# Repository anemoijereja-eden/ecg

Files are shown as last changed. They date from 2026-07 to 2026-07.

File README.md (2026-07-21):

E.D.E.N.Tech Open Source Hardware health telemetry system
This project aims to bring the features of medical grade wireless telemetry systems to the people, making them vastly more compact and lowering costs significantly.
Where the average medical grade device that does what this unit can costs hundreds of dollars and only supports proprietary EMR systems, this device uses commodity parts and is intended to connect to an open source telemetry system based on InfluxDB.

Current work completed:
- Signal acquisition using an esp32-s3
- Off device signal processing
- first revision PCB design

To Do:
- Move signal processing onto the device itself
- enable device to report data over the network
- finish PCB designs and create the actual device
- create software solution for processing telemetry data on a recieving server
- Look into other telemetry to integrate

Potential ideas:
- non-invasive blood pressure monitor built more compact than ever before using a PCB motor, integrated cycloidal drive, and a membrane pump to create the full system at a pcb scale.
- integration with implanted sensors via nfc

Tech Stack:
The system is based around the AD8232 as an analog frontend, connected to an ESP32-S3 microcontroller to create a low cost platform using parts that are already widely used and accepted in open hardware.
This repository contains an esp32 firmware, a kicad project under the "PCB" subdirectory, and the prototype off-device processing scripts in "plotter.py"

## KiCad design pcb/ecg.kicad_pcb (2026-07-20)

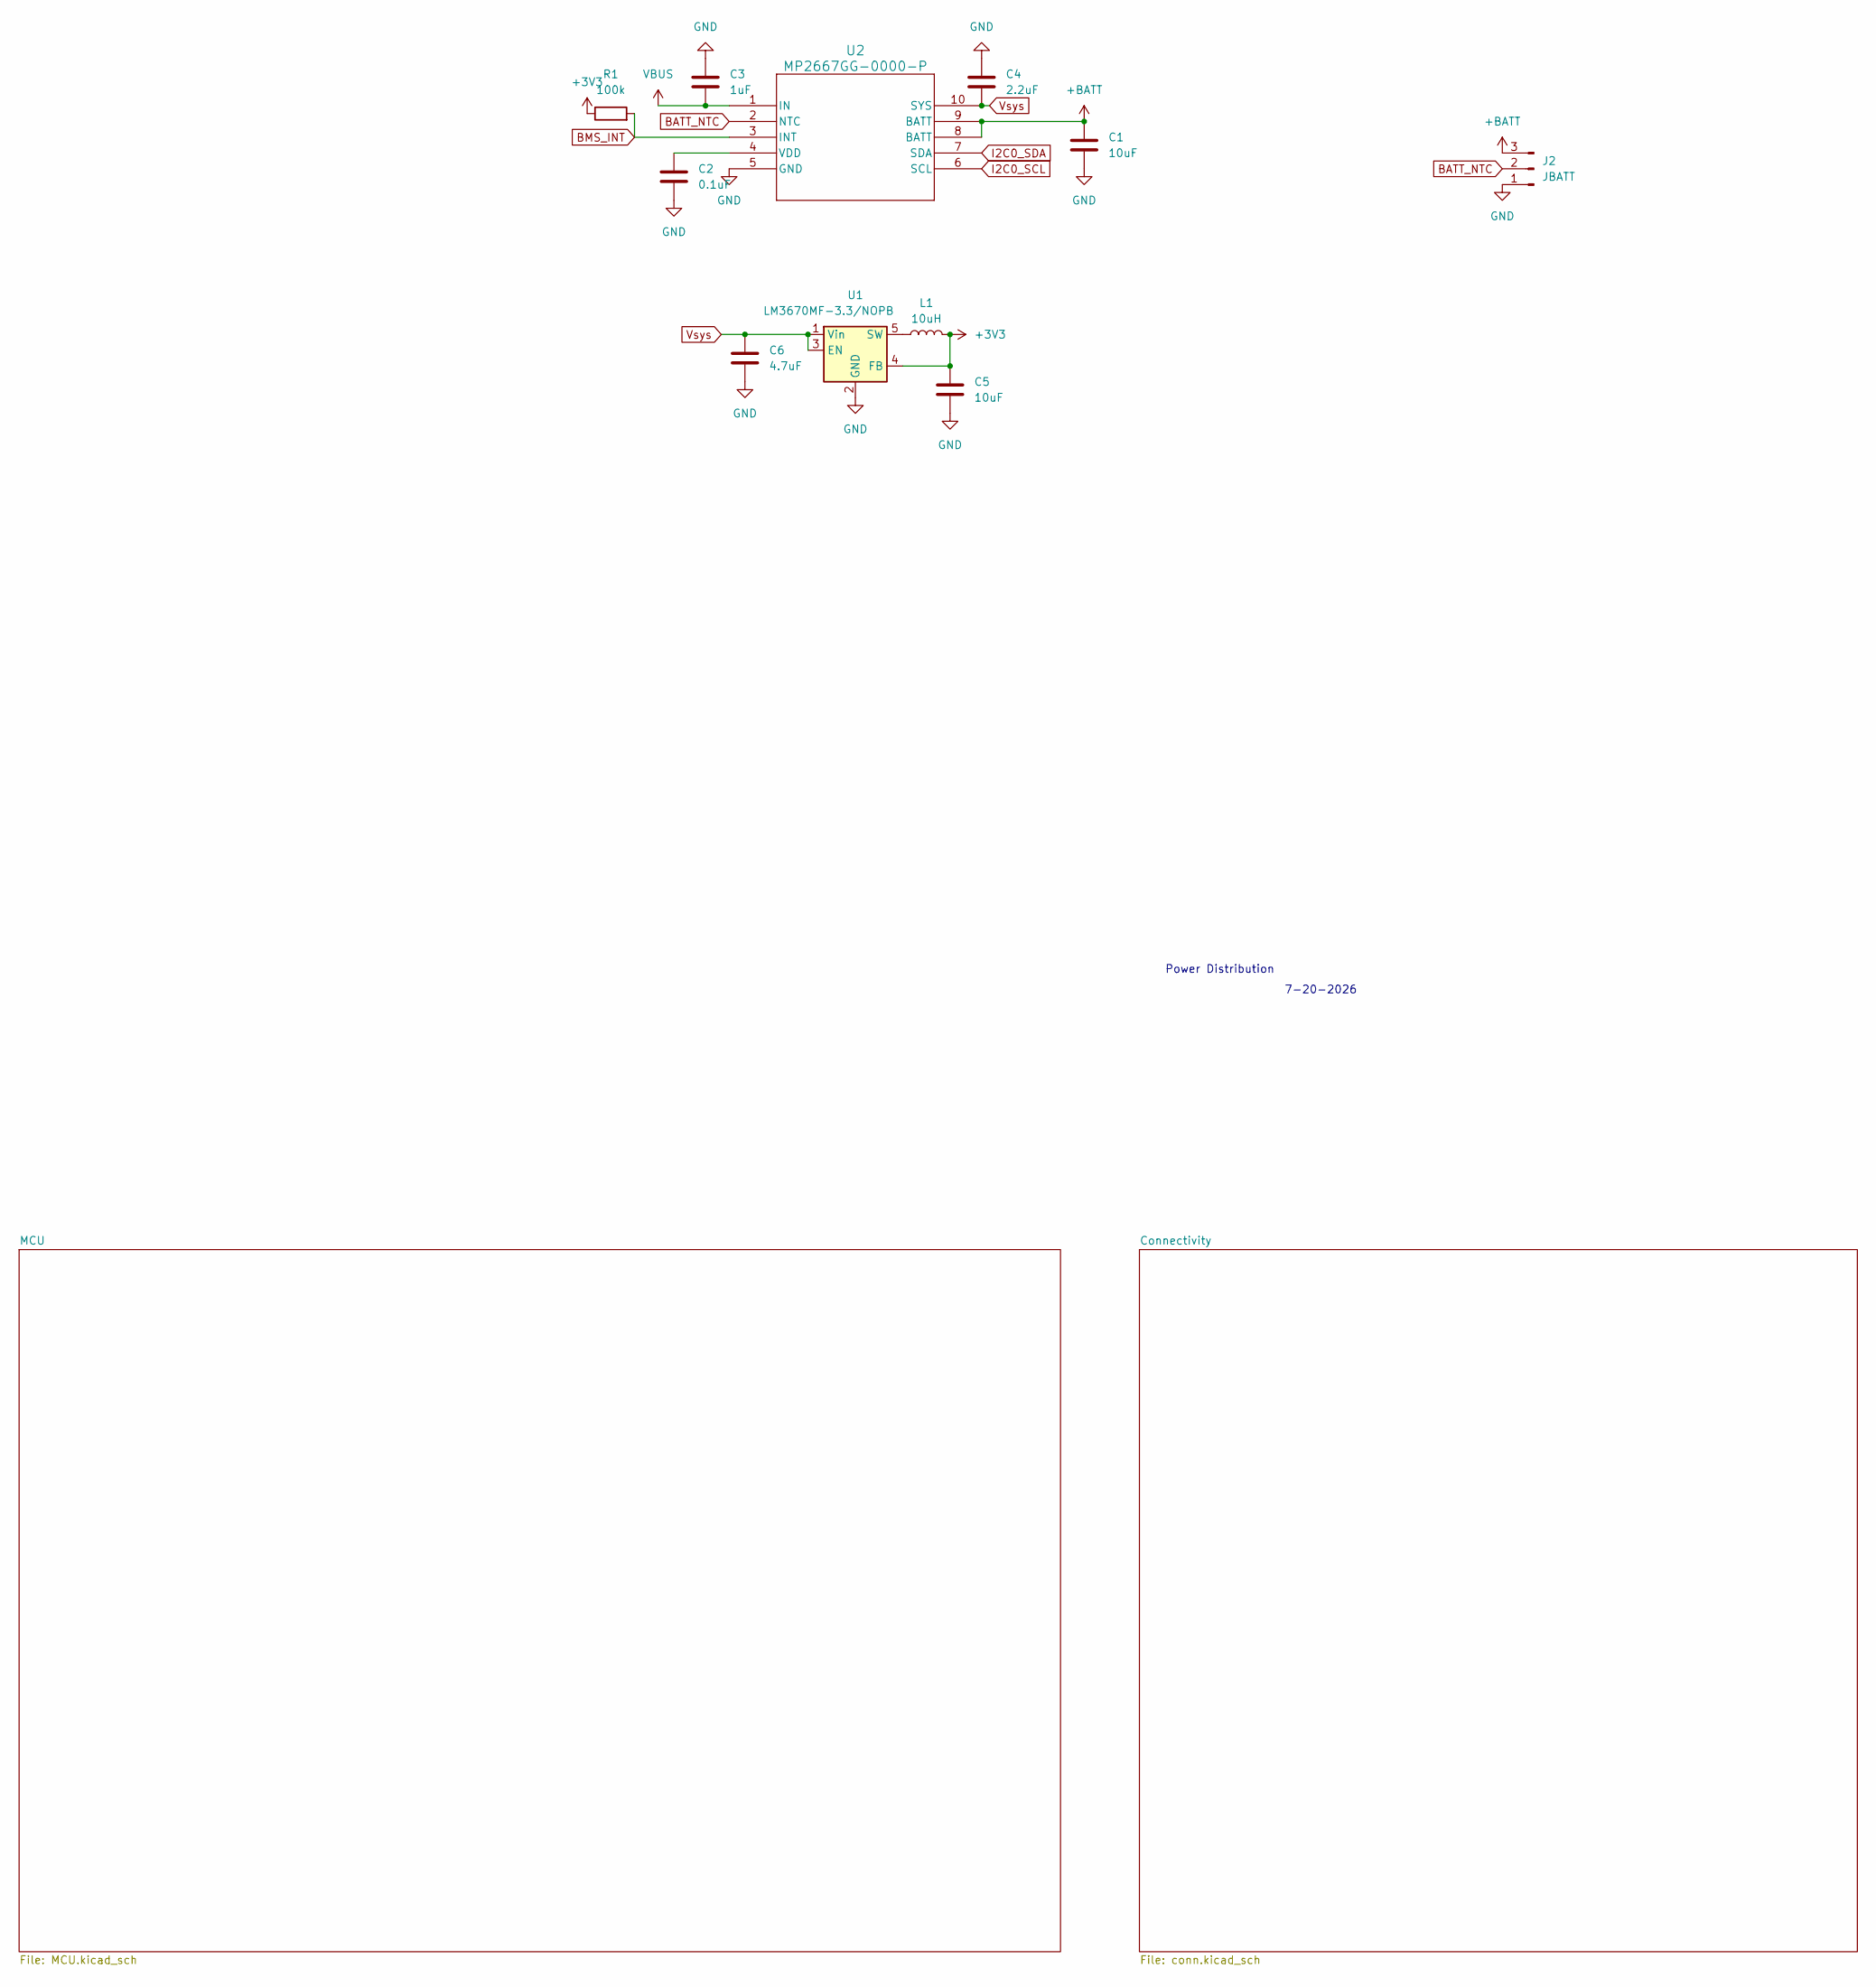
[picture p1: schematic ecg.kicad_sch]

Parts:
C1, C5: 10uF; C_0805_2012Metric_Pad1.18x1.45mm_HandSolder
C2: 0.1uF; C_0603_1608Metric_Pad1.08x0.95mm_HandSolder
C3: 1uF; C_0603_1608Metric_Pad1.08x0.95mm_HandSolder
C4: 2.2uF; C_0603_1608Metric_Pad1.08x0.95mm_HandSolder
C6: 4.7uF; C_0805_2012Metric_Pad1.18x1.45mm_HandSolder
J2: JBATT; PinHeader_1x03_P2.54mm_Horizontal
L1: 10uH; L_1210_3225Metric_Pad1.42x2.65mm_HandSolder
R1: 100k; R_0603_1608Metric_Pad0.98x0.95mm_HandSolder
U1: LM3670MF-3.3/NOPB; TSOT-23-5
U2: MP2667GG-0000-P; QFN-10_2MMx2MM_MNP

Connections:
+3V3: C5.1, L1.2, R1.1, U1.4 (FB); also elsewhere on the board
+BATT: C1.1, J2.3, U2.8 (BATT), U2.9 (BATT)
BATT_NTC: J2.2, U2.2 (NTC)
BMS_INT: R1.2, U2.3 (INT); also elsewhere on the board
GND: C1.2, C2.2, C3.1, C4.1, C5.2, C6.2, J2.1, U1.2 (GND), U2.5 (GND); also elsewhere on the board
I2C0_SCL: U2.6 (SCL); also elsewhere on the board
I2C0_SDA: U2.7 (SDA); also elsewhere on the board
unnamed: L1.1, U1.5 (SW)
unnamed: C2.1, U2.4 (VDD)
VBUS: C3.2, U2.1 (IN); also elsewhere on the board
Vsys: C4.2, C6.1, U1.1 (Vin), U1.3 (EN), U2.10 (SYS)

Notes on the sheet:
Power Distribution
7-20-2026

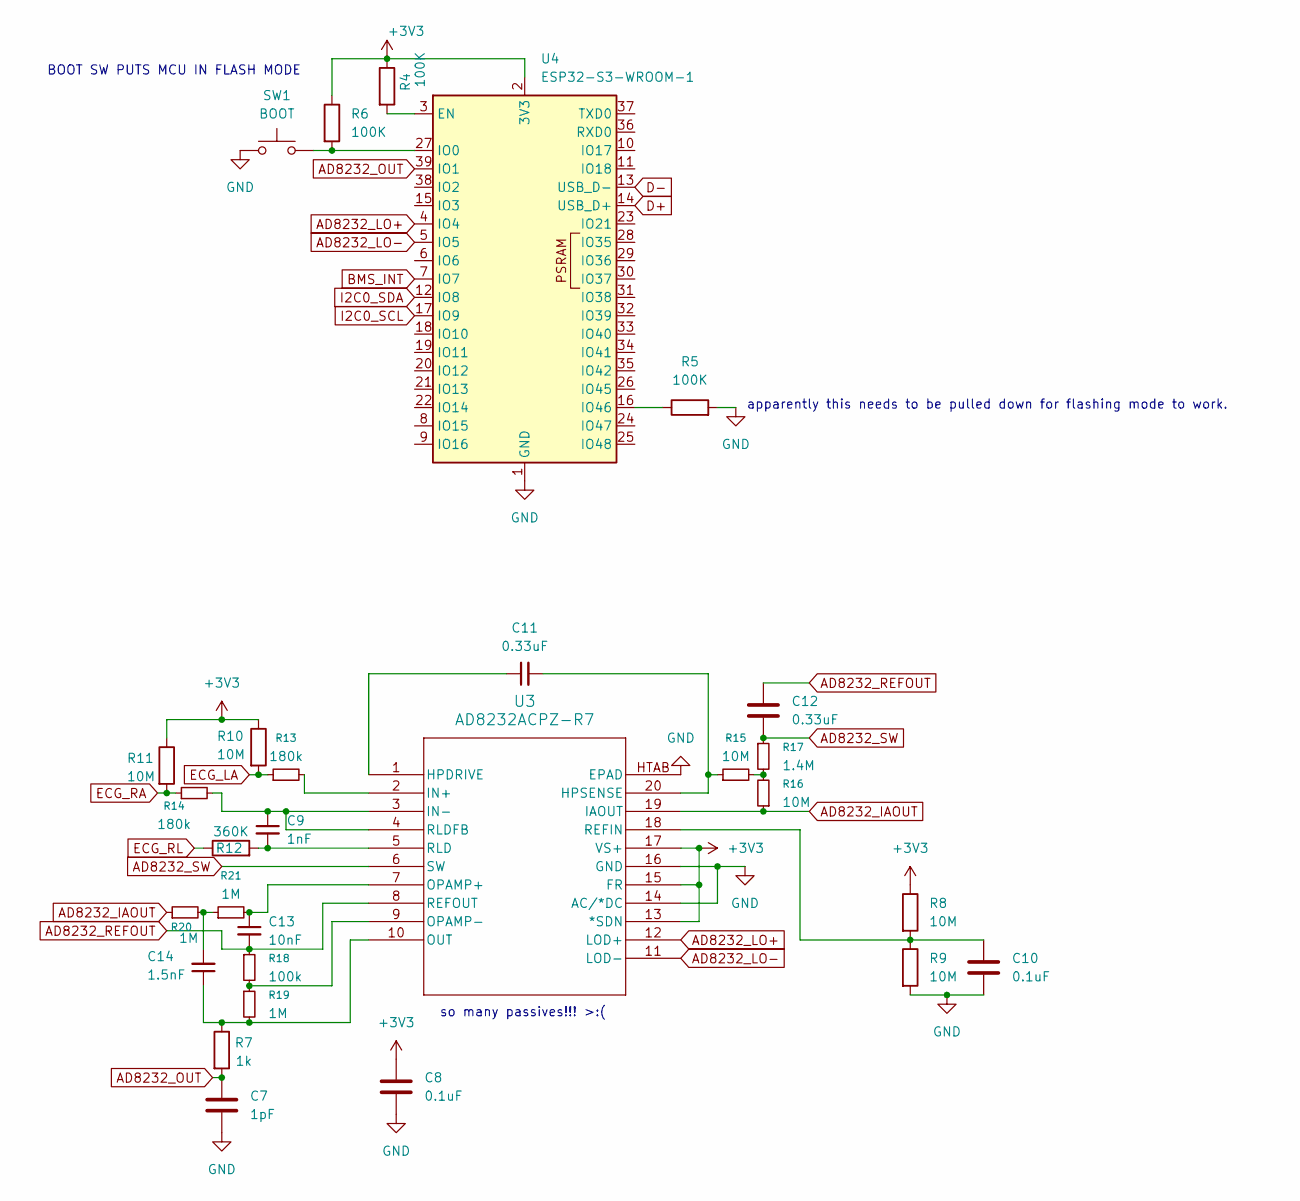
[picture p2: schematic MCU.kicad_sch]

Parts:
C7: 1pF; C_0603_1608Metric_Pad1.08x0.95mm_HandSolder
C8, C10: 0.1uF; C_0603_1608Metric_Pad1.08x0.95mm_HandSolder
C9: 1nF; C_0603_1608Metric_Pad1.08x0.95mm_HandSolder
C11, C12: 0.33uF; C_0603_1608Metric_Pad1.08x0.95mm_HandSolder
C13: 10nF; C_0603_1608Metric_Pad1.08x0.95mm_HandSolder
C14: 1.5nF; C_0603_1608Metric_Pad1.08x0.95mm_HandSolder
R4, R5, R6: 100K; R_0603_1608Metric_Pad0.98x0.95mm_HandSolder
R7: 1k; R_0603_1608Metric_Pad0.98x0.95mm_HandSolder
R8, R9, R10, R11, R15, R16: 10M; R_0603_1608Metric_Pad0.98x0.95mm_HandSolder
R12: 360K; R_0603_1608Metric_Pad0.98x0.95mm_HandSolder
R13, R14: 180k; R_0603_1608Metric_Pad0.98x0.95mm_HandSolder
R17: 1.4M; R_0603_1608Metric_Pad0.98x0.95mm_HandSolder
R18: 100k; R_0603_1608Metric_Pad0.98x0.95mm_HandSolder
R19, R20, R21: 1M; R_0603_1608Metric_Pad0.98x0.95mm_HandSolder
SW1: BOOT; SW_Push_1P1T_NO_CK_KMR2
U3: AD8232ACPZ-R7; CP_20_10_ADI
U4: ESP32-S3-WROOM-1

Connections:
+3V3: C8.1, R4.1, R6.1, R8.1, R10.1, R11.1, U3.13 (*SDN), U3.15 (FR), U3.17 (VS+), U4.2 (3V3); also elsewhere on the board
AD8232_IAOUT: R16.1, R20.1, U3.19 (IAOUT)
AD8232_LO+: U3.12 (LOD+), U4.4 (IO4)
AD8232_LO-: U3.11 (LOD-), U4.5 (IO5)
AD8232_OUT: C7.1, R7.2, U4.39 (IO1)
AD8232_REFOUT: C12.1, C13.2, R18.1, U3.8 (REFOUT)
AD8232_SW: C12.2, R17.1, U3.6 (SW)
BMS_INT: U4.7 (IO7); also elsewhere on the board
D+: U4.14 (USB_D+); also elsewhere on the board
D-: U4.13 (USB_D-); also elsewhere on the board
ECG_LA: R10.2, R13.1; also elsewhere on the board
ECG_RA: R11.2, R14.1; also elsewhere on the board
ECG_RL: R12.1; also elsewhere on the board
GND: C7.2, C8.2, C10.2, R5.2, R9.2, SW1.1, U3.14 (AC/*DC), U3.16 (GND), U3.HTAB (EPAD), U4.1 (GND), U4.40 (GND), U4.41 (GND); also elsewhere on the board
I2C0_SCL: U4.17 (IO9); also elsewhere on the board
I2C0_SDA: U4.12 (IO8); also elsewhere on the board
unnamed: C14.2, R20.2, R21.1
unnamed: R15.2, R16.2, R17.2
unnamed: C11.1, U3.1 (HPDRIVE)
unnamed: C11.2, R15.1, U3.20 (HPSENSE)
unnamed: R13.2, U3.2 (IN+)
unnamed: C9.1, R14.2, U3.3 (IN-), U3.4 (RLDFB)
unnamed: C13.1, R21.2, U3.7 (OPAMP+)
unnamed: R18.2, R19.1, U3.9 (OPAMP-)
unnamed: C14.1, R7.1, R19.2, U3.10 (OUT)
unnamed: C10.1, R8.2, R9.1, U3.18 (REFIN)
unnamed: C9.2, R12.2, U3.5 (RLD)
unnamed: R4.2, U4.3 (EN)
unnamed: R6.2, SW1.2, U4.27 (IO0)
unnamed: R5.1, U4.16 (IO46)

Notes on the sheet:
apparently this needs to be pulled down for flashing mode to work.
so many passives!!! >:(
BOOT SW PUTS MCU IN FLASH MODE

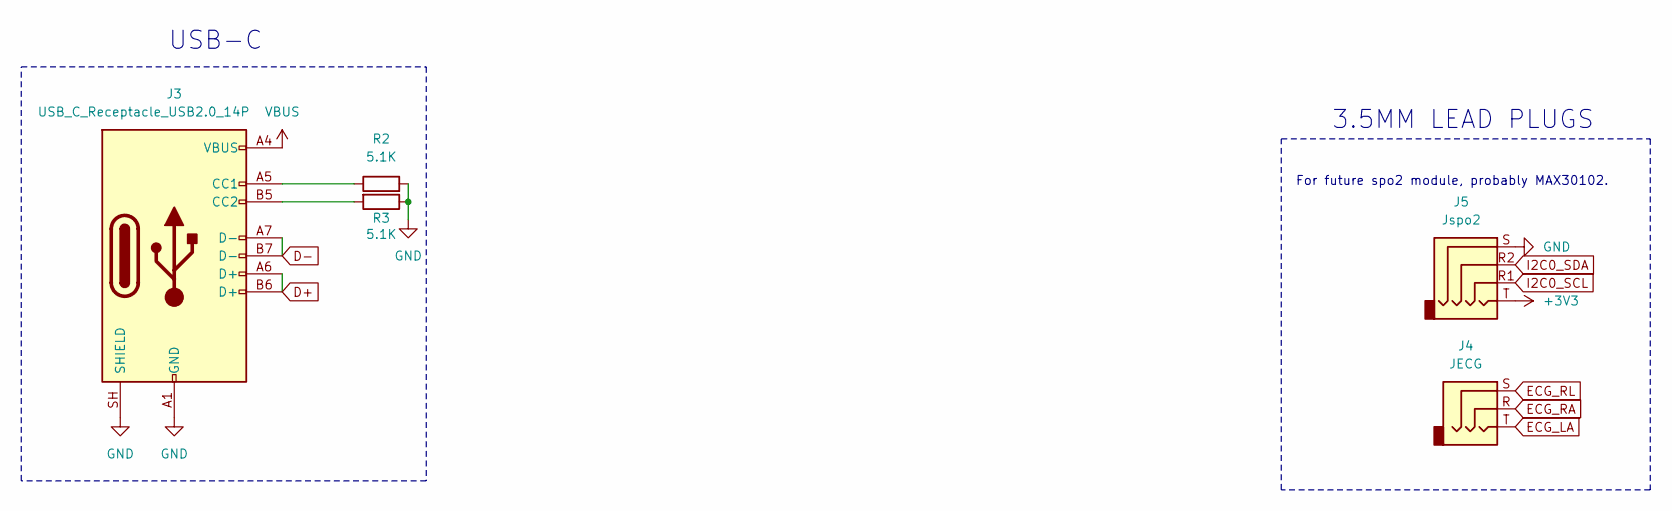
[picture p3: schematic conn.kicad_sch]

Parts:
J3: USB_C_Receptacle_USB2.0_14P; USB_C_Receptacle_HCTL_HC-TYPE-C-16P-01A
J4: JECG; Jack_3.5mm_CUI_SJ-3523-SMT_Horizontal
J5: Jspo2; Jack_3.5mm_CUI_SJ-3524-SMT_Horizontal
R2, R3: 5.1K; R_0603_1608Metric_Pad0.98x0.95mm_HandSolder

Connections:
+3V3: J5.T; also elsewhere on the board
D+: J3.A6 (D+), J3.B6 (D+); also elsewhere on the board
D-: J3.A7 (D-), J3.B7 (D-); also elsewhere on the board
ECG_LA: J4.T; also elsewhere on the board
ECG_RA: J4.R; also elsewhere on the board
ECG_RL: J4.S; also elsewhere on the board
GND: J3.A1 (GND), J3.A12 (GND), J3.B1 (GND), J3.B12 (GND), J3.SH (SHIELD), J5.S, R2.2, R3.1; also elsewhere on the board
unnamed: J3.A5 (CC1), R2.1
unnamed: J3.B5 (CC2), R3.2
VBUS: J3.A4 (VBUS), J3.A9 (VBUS), J3.B4 (VBUS), J3.B9 (VBUS); also elsewhere on the board

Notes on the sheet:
For future spo2 module, probably MAX30102.
3.5MM LEAD PLUGS
USB-C

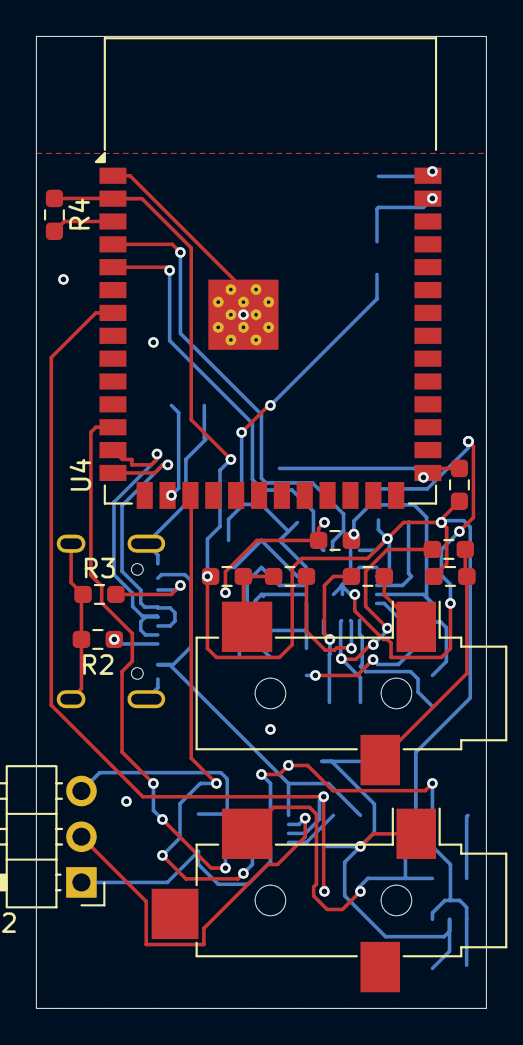
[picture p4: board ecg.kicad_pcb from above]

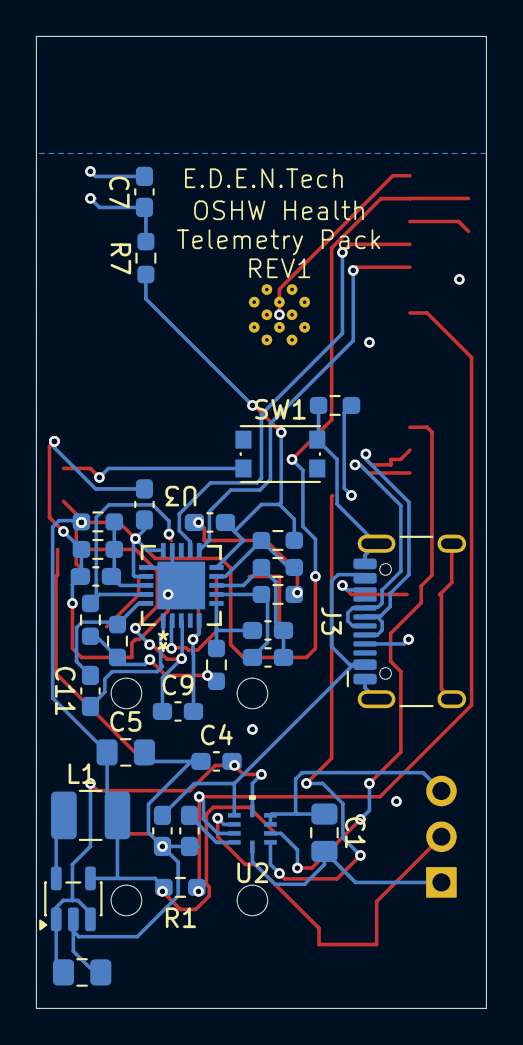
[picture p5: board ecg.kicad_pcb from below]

Board: 2 copper layers, 25.0 x 54.0 mm, 45 parts (31 on the bottom side), 38 nets.

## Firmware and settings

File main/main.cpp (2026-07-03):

#include <stdio.h>
#include <string.h>
#include "freertos/FreeRTOS.h"
#include "freertos/task.h"
#include "esp_adc/adc_continuous.h"
#include "esp_task_wdt.h"
#include "hal/adc_types.h"

#include "esp_dsp.h"

#define SAMPLE_FREQ_HZ               1000  // 1 kHz sampling rate
#define READ_LEN                     16    // 32 bytes = 8 samples per frame

static TaskHandle_t s_adc_task_handle = NULL;

// DMA Event Callback: Notifies our dedicated task when a conversion frame is ready
static bool IRAM_ATTR adc_coex_cb(adc_continuous_handle_t handle, const adc_continuous_evt_data_t *edata, void *user_data)
{
    BaseType_t mustYield = pdFALSE;
    if (s_adc_task_handle != NULL) {
        vTaskNotifyGiveFromISR(s_adc_task_handle, &mustYield);
    }
    return mustYield;
}

// ADC Pool Overflow Callback
static bool IRAM_ATTR adc_on_pool_ovf_cb(adc_continuous_handle_t handle, const adc_continuous_evt_data_t *edata, void *user_data)
{
    esp_rom_printf("\nW: ADC Pool Overflow");
    return false;
}

// The dedicated processing task pinned entirely to Core 1
void adc_plot_task(void *pvParameters)
{
    // Capture our own task handle so the ISR callback can notify us
    s_adc_task_handle = xTaskGetCurrentTaskHandle();

    // 1. Initialize Continuous Mode Driver Handle
    adc_continuous_handle_t adc_handle = NULL;
    adc_continuous_handle_cfg_t adc_config = {
        .max_store_buf_size = 1024,
        .conv_frame_size = READ_LEN,
        .flags = {
            .flush_pool = 1,
        },
    };
    ESP_ERROR_CHECK(adc_continuous_new_handle(&adc_config, &adc_handle));

    // 2. Configure the ADC Channel Patterns
    adc_digi_pattern_config_t adc_patterns[1];
    adc_digi_pattern_config_t adc_pattern_1 = {
        .atten = ADC_ATTEN_DB_12,
        .channel = ADC_CHANNEL_3,
        .unit = ADC_UNIT_1,
        .bit_width = ADC_BITWIDTH_12,
    };
    adc_patterns[0] = adc_pattern_1;

    adc_continuous_config_t dig_cfg = {
        .pattern_num = 1,
        .adc_pattern = adc_patterns, 
        .sample_freq_hz = SAMPLE_FREQ_HZ,
        .conv_mode = ADC_CONV_SINGLE_UNIT_1,
        .format = ADC_DIGI_OUTPUT_FORMAT_TYPE2, 
    };

    
    ESP_ERROR_CHECK(adc_continuous_config(adc_handle, &dig_cfg));

    // 3. Register Callback and Start ADC
    adc_continuous_evt_cbs_t cbs = {
        .on_conv_done = adc_coex_cb,
        .on_pool_ovf = adc_on_pool_ovf_cb
    };
    ESP_ERROR_CHECK(adc_continuous_register_event_callbacks(adc_handle, &cbs, NULL));
    ESP_ERROR_CHECK(adc_continuous_start(adc_handle));

    // 4. Register this specific task with the Core 1 Watchdog (TWDT)
    ESP_ERROR_CHECK(esp_task_wdt_add(s_adc_task_handle));

    uint8_t result[READ_LEN] = {0};
    uint32_t ret_num = 0;

    while (1) {
        // Wait until the DMA fills a frame (Blocks efficiently without burning CPU)
        ulTaskNotifyTake(pdTRUE, portMAX_DELAY);

        esp_err_t ret = adc_continuous_read(adc_handle, result, READ_LEN, &ret_num, 0);
        if (ret == ESP_OK) {
            constexpr size_t MAX_SAMPLES = READ_LEN / SOC_ADC_DIGI_RESULT_BYTES;
            adc_continuous_data_t parsed_data[MAX_SAMPLES];
            uint32_t num_parsed = 0;

            if (adc_continuous_parse_data(adc_handle, result, ret_num, parsed_data, &num_parsed) == ESP_OK) {
                for (int i = 0; i < num_parsed; i++) {
                    printf("%d\n", (int)parsed_data[i].raw_data);
                }
            }
        }

        // Feed the watchdog for this task specifically
        esp_task_wdt_reset();

        // Yield momentarily to let IDLE1 execute on Core 1
        vTaskDelay(pdMS_TO_TICKS(1));
    }

    // Clean up if the loop ever breaks (unreachable here)
    esp_task_wdt_delete(s_adc_task_handle);
    adc_continuous_stop(adc_handle);
    adc_continuous_deinit(adc_handle);
    vTaskDelete(NULL);
}

extern "C" {
    void app_main(void)
    {
        // Create the ADC plotting task
        // Parameters: Task Function, Name, Stack Size (bytes), Params, Priority, Handle, Core ID (1)
        xTaskCreatePinnedToCore(
            adc_plot_task, 
            "adc_plot_task", 
            4096, 
            NULL, 
            5, 
            NULL, 
            1
        );

        // app_main runs on Core 0. Since its job is done, we can just let it delete itself.
        // This removes it from the task scheduler completely.
        vTaskDelete(NULL);
    }
}

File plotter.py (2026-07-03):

import serial
import threading
import collections
import numpy as np
from scipy.signal import butter, iirnotch, lfilter
import matplotlib.pyplot as plt
import matplotlib.animation as animation

# PLOTTER
# This python script is a rough prototype that pulls a raw ecg trace over serial.
# It's designed to test processing techniques before they're ported over to the mcu.

# --- CONFIGURATION ---
SERIAL_PORT = '/dev/ttyACM0'         # Change to your exact port ('/dev/ttyUSB0' on Linux)
BAUD_RATE = 2000000           # Match your ESP-IDF configuration
ECG_WINDOW = 2000            # Show 1 second of live wave data on screen
TREND_WINDOW = 30            # Store the last 30 beats for metrics calculation
# ---------------------

# Ring buffers for the data used
ecg_buffer = collections.deque(maxlen=ECG_WINDOW)
bpm_buffer = collections.deque(maxlen=TREND_WINDOW)
hrv_buffer = collections.deque(maxlen=TREND_WINDOW)
rr_buffer = collections.deque(maxlen=TREND_WINDOW)
is_running = True

class AdvancedECGProcessor:
    def __init__(self, fs=1000.0):
        self.fs = fs
        
        # 1. Digital Filter Stages (0.5Hz - 40Hz Bandpass + 60Hz Notch)
        b_hp, a_hp = butter(1, 0.5, btype='high', fs=self.fs)
        self.hp_state = np.zeros(max(len(b_hp), len(a_hp)) - 1)
        self.b_hp, self.a_hp = b_hp, a_hp

        b_notch, a_notch = iirnotch(60.0, 30.0, fs=self.fs)
        self.notch_state = np.zeros(max(len(b_notch), len(a_notch)) - 1)
        self.b_notch, self.a_notch = b_notch, a_notch

        b_lp, a_lp = butter(2, 40.0, btype='low', fs=self.fs)
        self.lp_state = np.zeros(max(len(b_lp), len(a_lp)) - 1)
        self.b_lp, self.a_lp = b_lp, a_lp

        # R-Peak & Metric Tracking Buffers
        self.threshold = 1000.0  
        self.cooldown_samples = int(0.3 * self.fs)
        self.cooldown_counter = 0
        self.sample_counter = 0
        
        self.r_peak_times = []      # Timestamps of recent peaks (in seconds)
        self.r_peak_amplitudes = [] # Peak heights for EDR estimation
        self.rr_intervals = []      # Inter-beat intervals (in milliseconds)

    def process_sample(self, raw_sample):
        self.sample_counter += 1
        if self.cooldown_counter > 0:
            self.cooldown_counter -= 1

        # Feed the cascaded filter chain
        clean, self.hp_state = lfilter(self.b_hp, self.a_hp, [raw_sample], zi=self.hp_state)
        clean, self.notch_state = lfilter(self.b_notch, self.a_notch, clean, zi=self.notch_state)
        clean, self.lp_state = lfilter(self.b_lp, self.a_lp, clean, zi=self.lp_state)
        filtered_val = float(clean[0])

        metrics = {"bpm": None, "hrv": None, "rr": None}

        # Peak Detection Check
        if filtered_val > self.threshold and self.cooldown_counter == 0:
            current_time_sec = self.sample_counter / self.fs
            
            if len(self.r_peak_times) > 0:
                last_time_sec = self.r_peak_times[-1]
                ibi_ms = (current_time_sec - last_time_sec) * 1000.0 # Interval in ms
                
                # Filter out impossible biometric intervals (40-200 BPM equivalent)
                if 300.0 <= ibi_ms <= 1500.0:
                    self.r_peak_times.append(current_time_sec)
                    self.r_peak_amplitudes.append(filtered_val)
                    self.rr_intervals.append(ibi_ms)
                    
                    # Keep local analytics tracking slices lean
                    if len(self.r_peak_times) > 40:
                        self.r_peak_times.pop(0)
                        self.r_peak_amplitudes.pop(0)
                        self.rr_intervals.pop(0)

                    # --- CALCULATE BIOMETRICS ---
                    # 1. Heart Rate (BPM)
                    metrics["bpm"] = 60000.0 / ibi_ms
                    
                    # 2. HRV (RMSSD calculation over last 5-10 beats)
                    if len(self.rr_intervals) >= 5:
                        diffs = np.diff(self.rr_intervals)
                        metrics["hrv"] = np.sqrt(np.mean(diffs ** 2))
                    
                    # 3. Respiration Rate (EDR calculation)
                    # We compute respiration frequency by measuring the cycling rate of the R-peak heights
                    if len(self.r_peak_times) >= 12:
                        times = np.array(self.r_peak_times)
                        amps = np.array(self.r_peak_amplitudes)
                        
                        # Detrend the amplitude variance to isolate breathing movements
                        amps_detrended = amps - np.mean(amps)
                        intervals = np.diff(times)
                        avg_ibi_sec = np.mean(intervals) if len(intervals) > 0 else 0.8
                        
                        # Count zero-crossings of the amplitude deviations to estimate breath cycles [4]
                        zero_crossings = np.where(np.diff(np.sign(amps_detrended)))[0]
                        total_time = times[-1] - times[0]
                        
                        if total_time > 0:
                            breaths = len(zero_crossings) / 2.0
                            calculated_rr = (breaths / total_time) * 60.0
                            if 6 <= calculated_rr <= 35: # Bound to normal human respiration scales [5]
                                metrics["rr"] = calculated_rr

            else:
                self.r_peak_times.append(current_time_sec)
                self.r_peak_amplitudes.append(filtered_val)

            self.cooldown_counter = self.cooldown_samples

        # Adaptive peak decay
        self.threshold = self.threshold * 0.995 + (filtered_val * 0.005 if filtered_val > 0 else 0)
        self.threshold = max(self.threshold, 200.0)

        return filtered_val, metrics

def serial_reader_thread():
    global is_running
    processor = AdvancedECGProcessor(fs=1000.0)
    
    try:
        ser = serial.Serial(SERIAL_PORT, BAUD_RATE, timeout=1)
        print(f"Reading telemetry from {SERIAL_PORT}...")
        ser.reset_input_buffer()
        
        while is_running:
            line = ser.readline().decode('utf-8', errors='ignore').strip()
            if line:
                try:
                    raw_val = int(line)
                    filtered_val, metrics = processor.process_sample(raw_val)
                    
                    ecg_buffer.append(filtered_val)
                    if metrics["bpm"] is not None:
                        bpm_buffer.append(metrics["bpm"])
                    if metrics["hrv"] is not None:
                        hrv_buffer.append(metrics["hrv"])
                    if metrics["rr"] is not None:
                        rr_buffer.append(metrics["rr"])
                except ValueError:
                    continue
    except serial.SerialException as e:
        print(f"Serial Link Closed: {e}")
    finally:
        is_running = False
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
